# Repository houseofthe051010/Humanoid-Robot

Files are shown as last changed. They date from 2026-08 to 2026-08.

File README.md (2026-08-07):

# Humanoid Robot

This is my project to build a human-sized bipedal robot. In this repo I have all my current designs for my robot's shin and lower leg, and the iterations of gearboxes I have made for my actuators.

Right now, I am using pre-made actuators and am waiting on a grant to further complete my robot.

This grant is for building and testing the robot's two lower-leg and ankle assemblies. It is the first stage of the humanoid and is not funding the complete robot.

This is the current prototype, showing both lower-leg assemblies side by side.

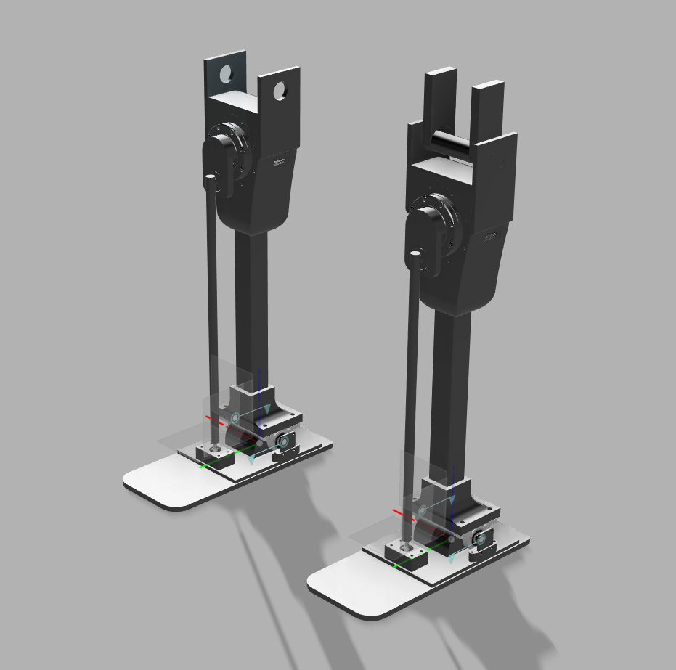
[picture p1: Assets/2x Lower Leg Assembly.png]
Two lower-leg prototype assemblies


## Electronics

Each ankle motor is controlled by a single-axis ODrive 3.6 clone. Both ODrives share one CAN bus with an STM32F103. The ODrives run the motor-control loops; the STM32 relays position commands from a Raspberry Pi 5 over SPI. UART is available for setup and debugging.

This is a wiring diagram of how i'll utilize CAN buses for each motor [`Schematics/`](Schematics/).

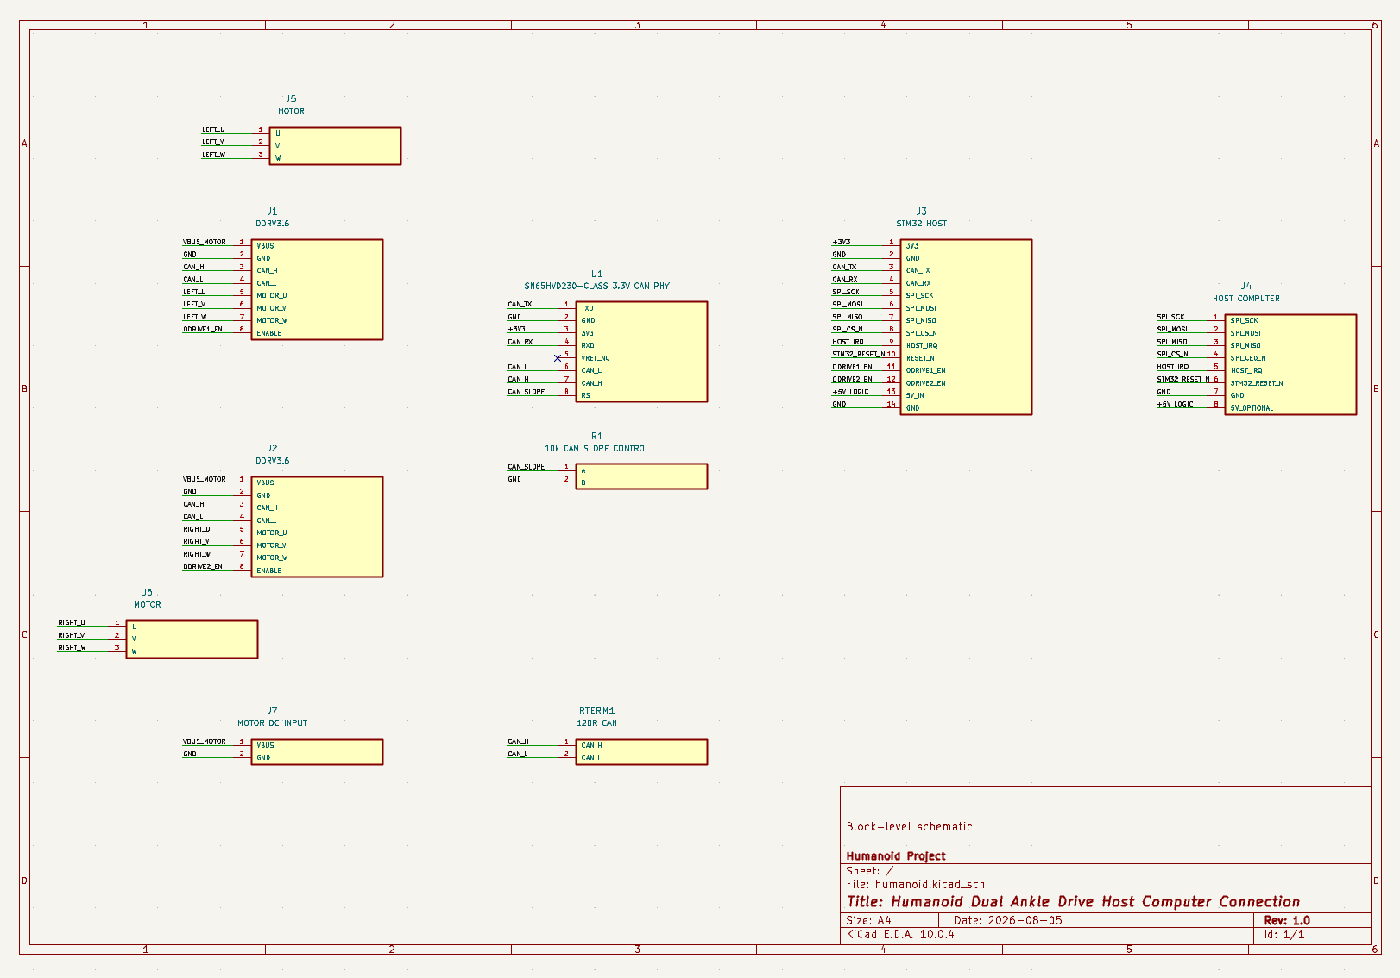
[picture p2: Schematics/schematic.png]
Electronics architecture


## Design

At first, I was thinking of a 2-DOF ankle design but now I am thinking of 1-DOF as its much cheaper and is really what I need. This came from a lot of thinking, as I am utilizing a lot of plastic for this build (though I will utilize aluminum in places where necessary). A lot of my body will be plastic and needs to be designed appropriately to support a bipedal's weight that is 5 foot tall. Currently I have a 1-dof ankle structure with a linkage system for only ankle pitch motion.

A bipedal can easily walk on level ground with ankle pitch. I have also attached a 50mm bearing hole for attaching the knee.

I also kept my earlier 2-DOF single-leg assembly as a backup in case I return to a 2-DOF ankle in the future.

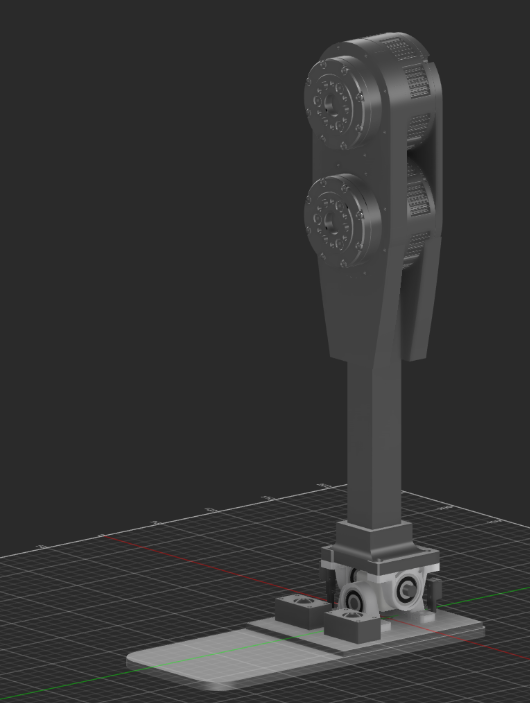
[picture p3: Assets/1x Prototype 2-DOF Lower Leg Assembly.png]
Backup 2-DOF lower-leg assembly


## Gearbox designs

The [`CAD/Actuators/`](CAD/Actuators/) folder has my custom planetary and cycloidal C6374 designs.

These gearboxes were built by me as a part of prototyping and learning on how to make my robot. They are there as they helped me decide how to make my robot and what actuators to use. I chose the cyclodial gearbox over the plantery in my design as it was easier to print with lower backlash, had high reductions, and was stronger, giving me 50+nm torque around 100mm size. Though, I chose to use a pre-built one as it was much less complex. 

## Bill of materials

This table shows the full replication cost. My current Macondo grant request is only $360 for the parts I still need; the rest are already owned or outside this grant request.

| Category | Item | Quantity | Unit price (USD) | Line total (USD) | Product link |
| --- | --- | ---: | ---: | ---: | --- |
| Actuation | SteadyWin GIM6010-48 48:1 planetary geared ankle motor, without driver | 2 | $156.00 | $312.00 | [Buy](https://rcdrone.top/products/steadywin-gim6010-48-planetary-reducer-servo-motor) |
| Structure | 6061-T6 aluminum square tubing, 1 in x 1 in x 0.125 in wall x 24 in | 2 | $14.89 | $29.78 | [Buy](https://www.onlinemetals.com/en/buy/aluminum/1-x-0-125-aluminum-square-tube-6061-t6-extruded/pid/18014) |
| Fabrication | SUNLU PA6-CF black filament, 1.75 mm, 1 kg, 80% PA / 20% carbon fiber | 1 | $44.99 | $44.99 | [Buy](https://store.sunlu.com/products/nylon6-carbon-fiber-pa6-cf-3d-printer-filament-1kg) |
| Mechanical | KP08 pillow block bearing, 8 mm bore | 10 | $2.95 | $29.50 | [Buy](https://www.crcibernetica.com/8-mm-pillow-block-mounted-ball-bearing-kp08/) |
| Mechanical | M3 stainless-steel bolt, nut, flat-washer and spring-washer assortment, 720 pieces | 1 | $9.99 | $9.99 | [Buy](https://www.amazon.com/dp/B0FG2BRXL3) |
| Motor control | ODrive S V3.6 FOC single-axis BLDC motor controller, 60 A, CAN/PWM | 2 | $31.61 | $63.22 | [Buy](https://www.banggood.com/ODrive-S-V3_6-FOC-BLDC-Motor-Controller-60A-Support-CAN-PWM-Pulse-Encoder-TLE5012B-AS5047-AMT10X-MT6816-ARM-Cortex-M4-p-2043307.html) |
| CAN bus | SN65HVD230 3.3 V CAN bus transceiver module | 1 | $0.94 | $0.94 | [Buy](https://www.aliexpress.com/item/1005008512626947.html) |
| CAN bus | 120 ohm 1/4 W 1% metal-film termination resistors, 100-pack | 1 | $0.94 | $0.94 | [Buy](https://www.aliexpress.com/item/32526023399.html) |
| Electronics | 10 kOhm 1/4 W metal-film resistors, 100-pack | 1 | $0.50 | $0.50 | [Buy](https://www.aliexpress.com/item/1005006006915852.html) |
| Power | XT60 male and female connector set, 5 pairs | 1 | $5.60 | $5.60 | [Buy](https://www.aliexpress.com/item/1005009991978695.html) |
| Wiring | Variable-AWG wire allowance | 1 | $20.00 | $20.00 | [Reference](https://www.aliexpress.com/item/4001131337448.html) |
| Embedded control | STM32F103C8T6 Blue Pill development board, pre-soldered | 1 | $8.99 | $8.99 | [Buy](https://shillehtek.com/products/shillehtek-pre-soldered-authentic-stm32f103c8t6-arm-stm32) |
| Host computing | Raspberry Pi 5 Desktop Kit, 8 GB (host computer, storage, power, cooling, and accessories) | 1 | $235.00 | $235.00 | [Buy](https://www.canakit.com/official-raspberry-pi-5-desktop-kit.html) |
| **Total** |  |  |  | **$761.45** |  |

## Assembly instructions

1. Print the parts in [`CAD/Assembly/Individual STLs/`](CAD/Assembly/Individual%20STLs/) using PA6-CF. The STL names match their source STEP names.
2. Fit the two `Foot Mounting Plate` parts and `Rounded Bearing Support` to the `Foot Base`, then install the purchased pillow-block bearings on the pitch axis.
3. Attach the `Shin Support Attachment` and cut the aluminum shin tube to 200 mm. Drill the tube from the CAD hole locations, then fasten it with M3 hardware.
4. Use the `Electronics Mounting Tray` and `Encoder Holder` parts for the controller and encoder mounting points. The `Lower Leg Support Assembly` STEP files can be used as reference assemblies.
5. Mount one motor and one ODrive to each lower leg. Confirm that both ankles move freely by hand before applying power.
6. Wire and test one motor at a time with the ankle unloaded. 

### Power and signal wiring

- Use a current-limited 50 V bench supply rated for at least 10 A per motor, or 20 A when both motors  run together.
- The 50 V rail connects only to the ODrive power inputs. Power the STM32, CAN transceiver, and Raspberry Pi from their voltage regulations with GND connections.
- Connect STM32 CAN to Odrive CAN, merging them as you connect them, and UART to host computer.

## STM32 controller firmware

This protocol is used for Odrive comms: [ODrive v3.x CANSimple protocol](https://github.com/odriverobotics/ODrive/tree/master/Firmware/communication/can). UART can also be used for testing.

The first ODrive uses CAN ID `0` and the second ID `1` at 500 kbit/s. The Raspberry Pi helper in controls them as the host [`Code/rpi_host/ankle_controller.py`](Code/rpi_host/ankle_controller.py) has position, enable, idle, and stop commands. This was used to test my custom gearboxes.

### Build and flash with ST-Link

Connect the ST-LINK to the STM32. 

```text
cd Code/stm32_controller
pio run
pio run -t upload
pio device monitor -b 115200
```

## Notes

This is a long project, and I don't think macondo runs long enough for me to complete it, which is why i'm completing the lower leg first, and then will add on in different hack club events.

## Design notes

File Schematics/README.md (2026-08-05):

# Electronics Schematic

This is a schematic of my electronics architecture and the wiring and connections between each component. It is not a PCB design because the PCBs are prebuilt and bought separately.

Electronics architecture

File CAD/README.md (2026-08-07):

# CAD

Source CAD and STEP files for the robot are here. The actuator gearbox designs are in [`Actuators/`](Actuators/), and the shin, ankle, and feet assembly is in [`Assembly/`](Assembly/).

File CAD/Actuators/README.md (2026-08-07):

# Actuators

This folder contains the source CAD and STEP files for the gearbox designs I'm developing for my C6374 motors.

## Print settings

- Material: PA6-CF
- Infill: 100%
- Walls: maximum
- Printer: Anycubic Kobra S1

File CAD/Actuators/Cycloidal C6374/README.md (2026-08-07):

# Cycloidal C6374 Gearbox

This is where you'll find the source CAD, STEP, and printable STL files for the cycloidal gearbox I designed for my C6374 motor.

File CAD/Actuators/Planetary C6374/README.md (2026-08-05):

# Planetary C6374 Gearbox

This is where you'll find the source CAD and STEP files for the planetary gearbox I designed for my C6374 motor.

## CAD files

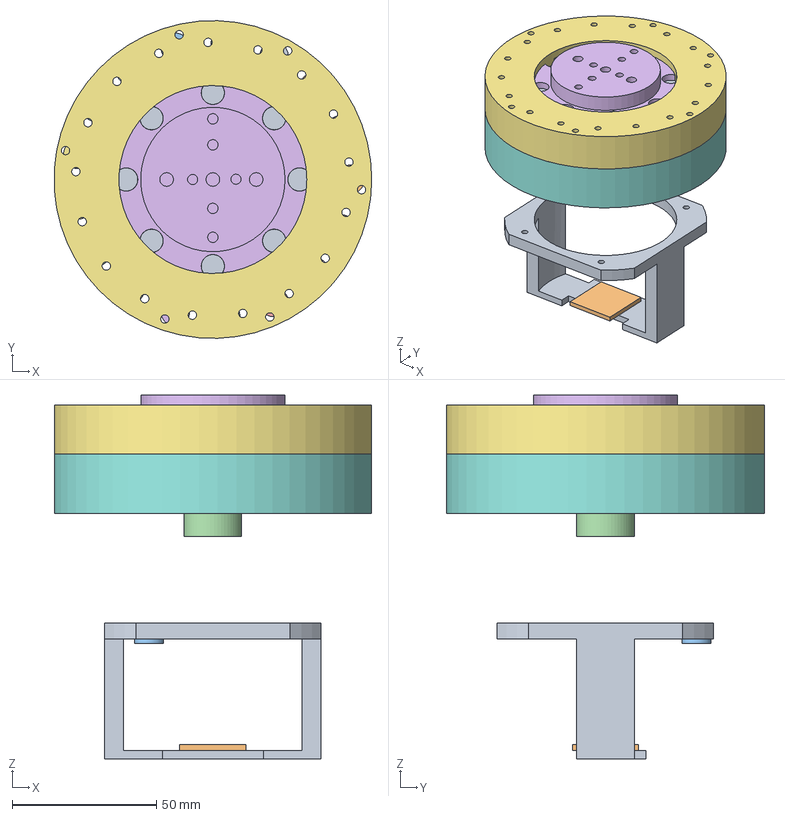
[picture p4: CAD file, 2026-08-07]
CAD/Actuators/Cycloidal C6374/Individual STEPs/10 - Cycloidal Output and Encoder Assembly.step
109.9 x 110.0 x 126.0 mm

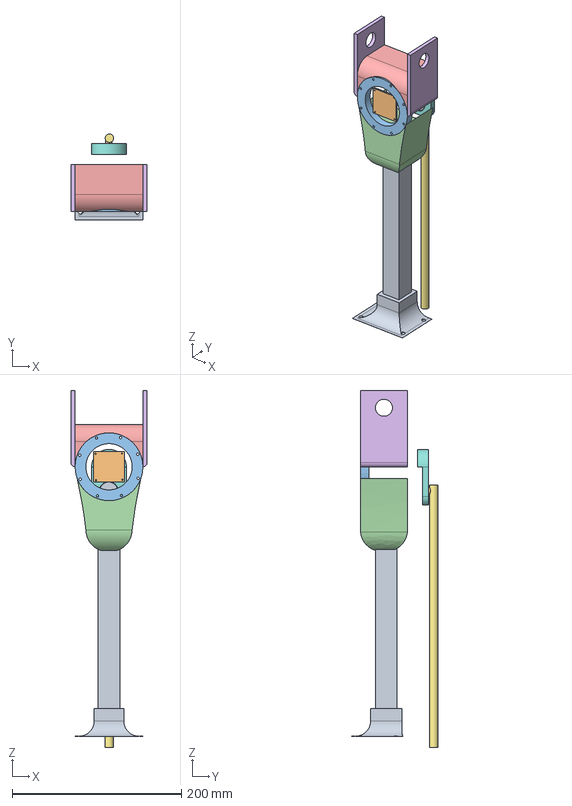
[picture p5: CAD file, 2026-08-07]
CAD/Assembly/Individual STEPs/16 - Lower Leg Support Assembly 1.step
90.0 x 101.6 x 421.3 mm

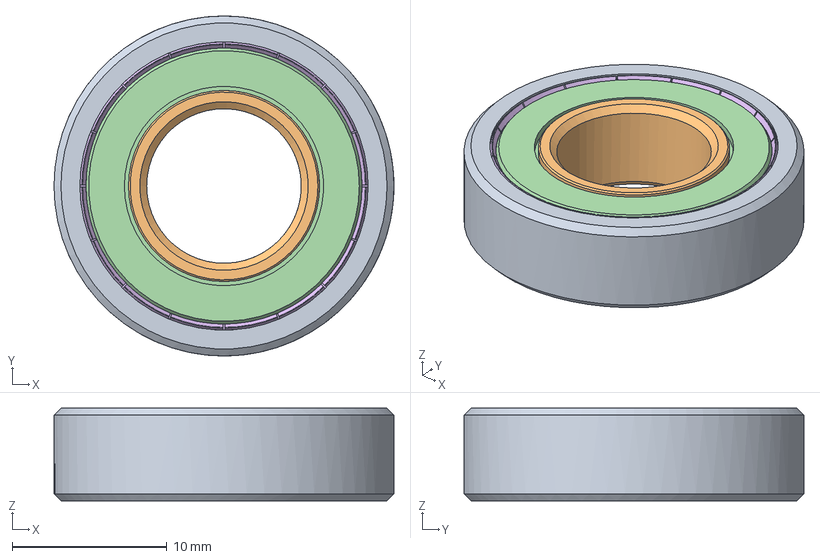
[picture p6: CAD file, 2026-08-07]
CAD/Actuators/Cycloidal C6374/Individual STEPs/07 - 6900Z Ball Bearing.step
22.0 x 22.0 x 6.00 mm

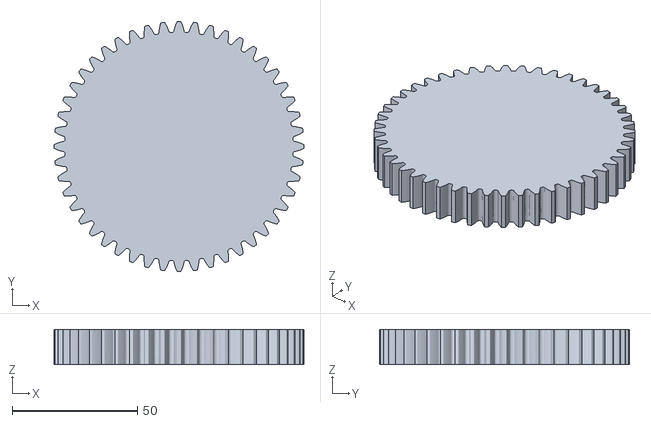
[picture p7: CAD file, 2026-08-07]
CAD/Actuators/Planetary C6374/Individual STLs/04 - Spur Gear - 48 Teeth.stl
100.0 x 100.0 x 14.0

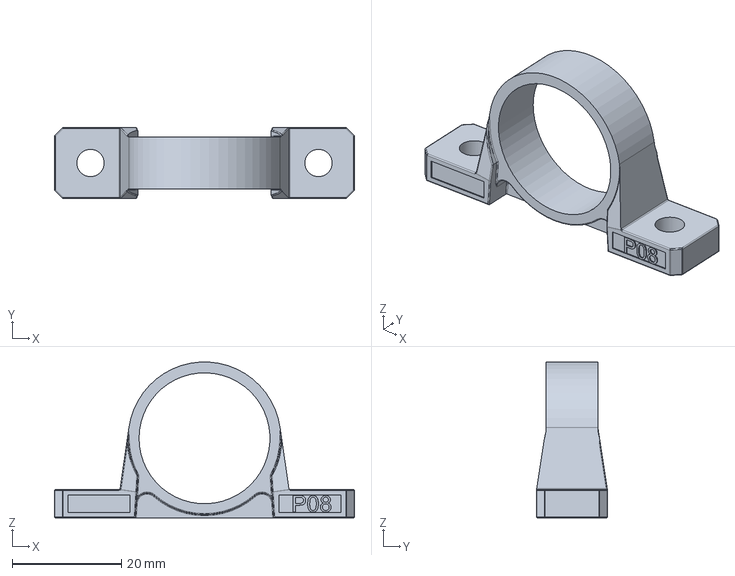
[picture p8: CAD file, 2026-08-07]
CAD/Assembly/Individual STEPs/10 - Pillow Block Bearing 1.step
55.0 x 13.0 x 28.6 mm

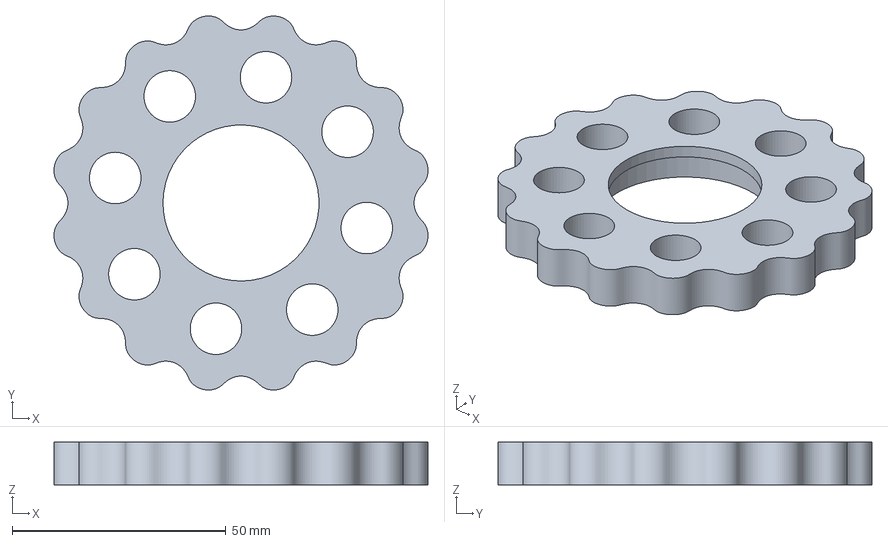
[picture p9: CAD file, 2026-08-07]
CAD/Actuators/Cycloidal C6374/Individual STEPs/05 - Cycloidal Disk 1.step
87.5 x 87.5 x 10.0 mm

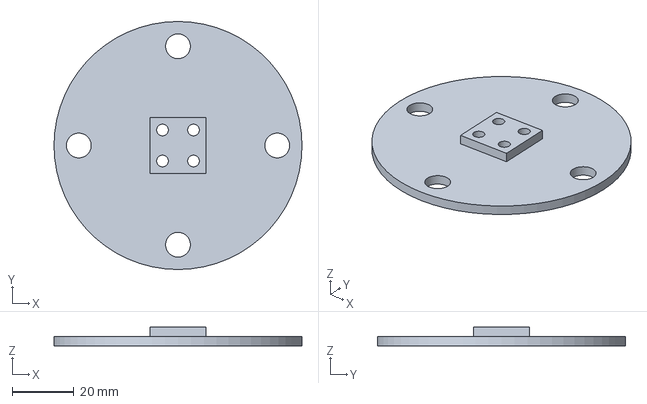
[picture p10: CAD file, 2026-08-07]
CAD/Actuators/Planetary C6374/Individual STEPs/09 - Motor Case Attachment.step
80.0 x 80.0 x 6.00 mm

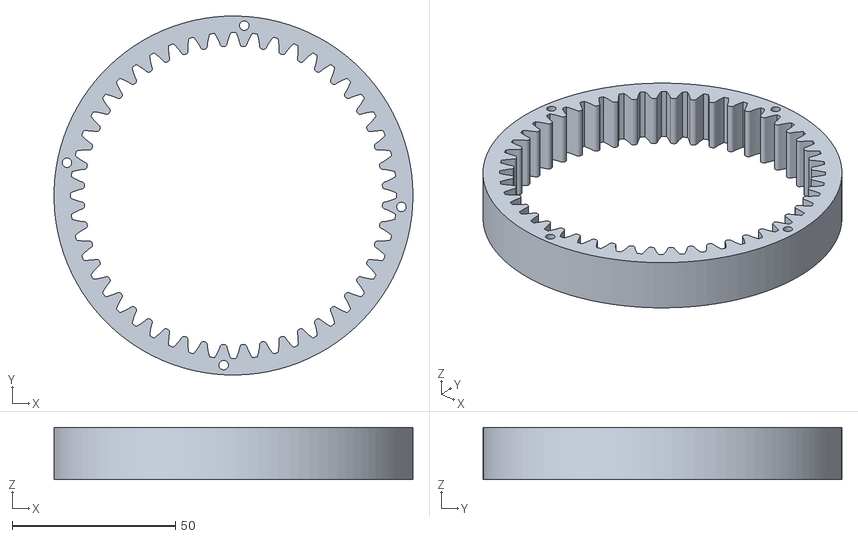
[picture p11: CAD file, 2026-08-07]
CAD/Actuators/Planetary C6374/Individual STLs/13 - Ring Shell.stl
110.0 x 110.0 x 16.0

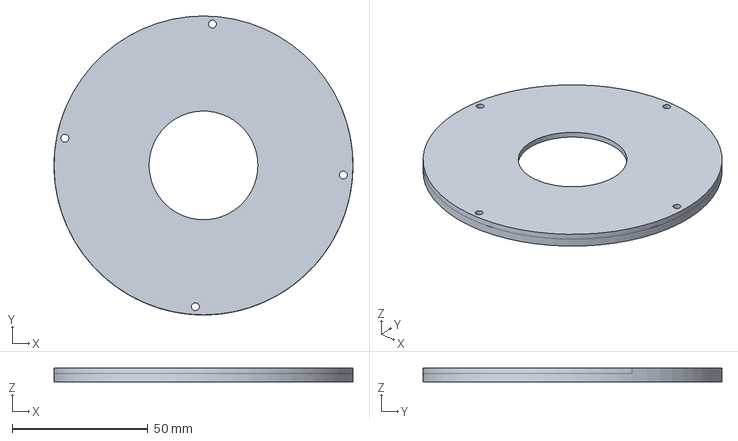
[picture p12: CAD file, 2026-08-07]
CAD/Actuators/Planetary C6374/Individual STEPs/11 - Middle Cover.step
110.0 x 110.0 x 5.00 mm

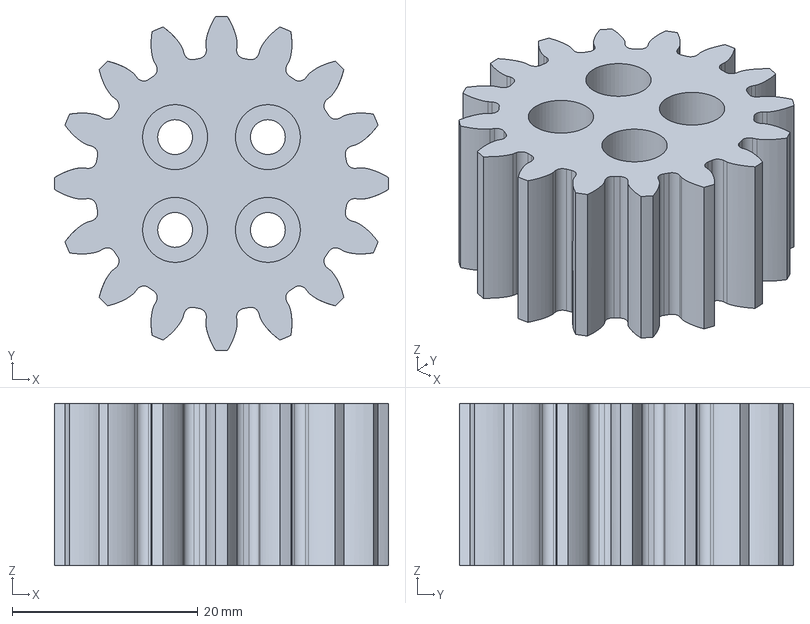
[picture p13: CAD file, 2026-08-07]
CAD/Actuators/Planetary C6374/Individual STEPs/07 - Second-Stage Sun Gear.step
36.0 x 36.0 x 17.5 mm

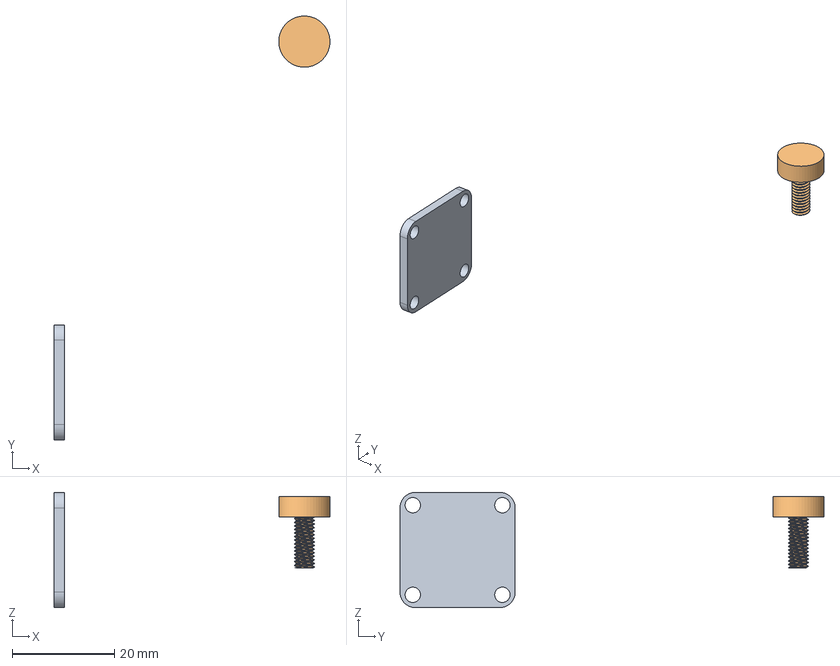
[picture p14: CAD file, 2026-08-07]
CAD/Assembly/Individual STEPs/20 - Encoder Holder 2.step
53.9 x 82.8 x 22.5 mm

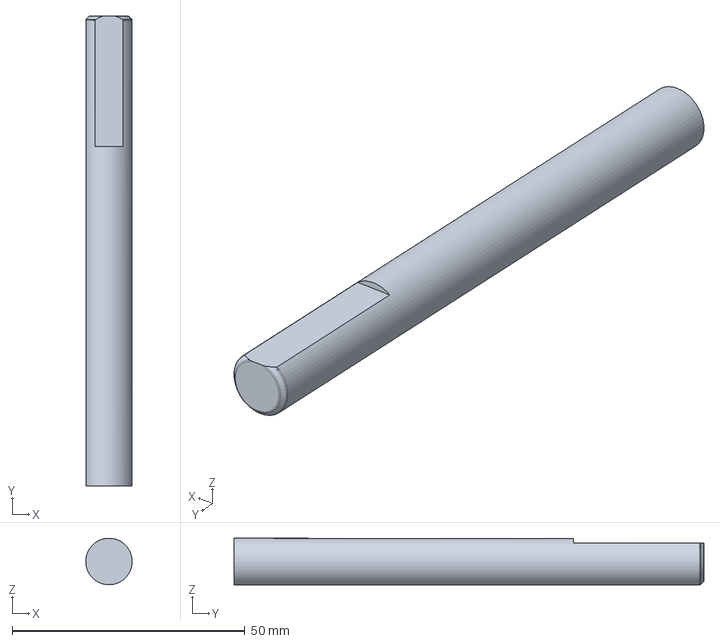
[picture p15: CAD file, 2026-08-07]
CAD/Actuators/Cycloidal C6374/Individual STEPs/08 - Eccentric Shaft.step
9.99 x 101.0 x 10.00 mm

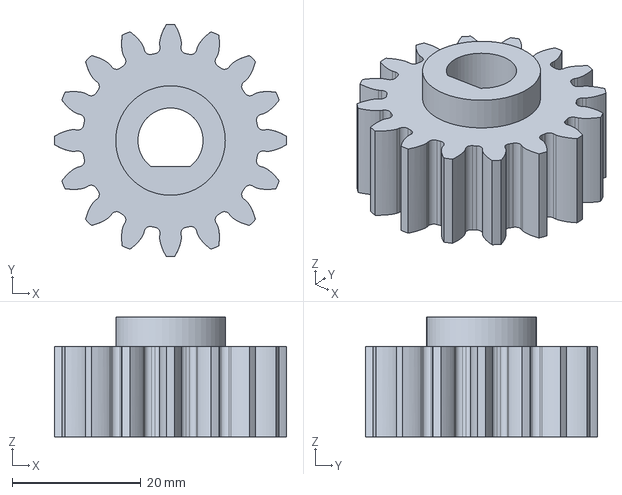
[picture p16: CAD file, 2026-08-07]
CAD/Actuators/Planetary C6374/Individual STEPs/06 - Sun Gear.step
36.0 x 36.0 x 18.6 mm

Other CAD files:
CAD/Assembly/Individual STEPs/21 - Lower Leg Support Assembly 2.step
CAD/Actuators/Planetary C6374/Individual STEPs/01 - 6900Z Ball Bearing.step
CAD/Assembly/Individual STEPs/17 - Pillow Block Bearing 3.step
CAD/Actuators/Cycloidal C6374/Individual STEPs/06 - Cycloidal Disk 2.step
CAD/Assembly/Individual STEPs/11 - Pillow Block Bearing 2.step
CAD/Actuators/Cycloidal C6374/Individual STEPs/01 - 6806RS Bearing.step
CAD/Actuators/Cycloidal C6374/Individual STEPs/03 - Cycloidal Gearbox Housing.step
CAD/Actuators/Cycloidal C6374/Individual STLs/03 - Cycloidal Gearbox Housing.stl
CAD/Actuators/Cycloidal C6374/Individual STLs/05 - Cycloidal Disk 1.stl
CAD/Actuators/Cycloidal C6374/Individual STLs/06 - Cycloidal Disk 2.stl
CAD/Actuators/Planetary C6374/Individual STEPs/02 - Gear Output Stabilizer Output Shaft.step
CAD/Actuators/Planetary C6374/Individual STEPs/05 - Planet Gear.step
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

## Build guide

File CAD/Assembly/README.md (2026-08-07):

# Shin, Ankle, and Feet Assembly

## Print settings

- Material: PA6-CF
- Infill: 100%
- Walls: maximum
- Printer: Anycubic Kobra S1

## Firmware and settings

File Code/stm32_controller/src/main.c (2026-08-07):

#include "stm32f1xx_hal.h"

#include <stdio.h>
#include <stdlib.h>
#include <string.h>

#include "odrive_can.h"

CAN_HandleTypeDef hcan;
SPI_HandleTypeDef hspi1;
UART_HandleTypeDef huart1;

enum {
    HOST_NOP = 0,
    HOST_MOVE_POSITION = 1,
    HOST_ENABLE = 2,
    HOST_IDLE = 3,
    HOST_ESTOP = 4,
    HOST_CLEAR_ERRORS = 5,
};

typedef struct __attribute__((packed)) {
    uint8_t magic;
    uint8_t command;
    uint8_t motor;
    uint8_t sequence;
    float position_turns;
    float velocity_ff_turns_s;
    float torque_ff_nm;
    uint8_t reserved[8];
} HostRequest;

typedef struct __attribute__((packed)) {
    uint8_t magic;
    uint8_t status;
    uint8_t last_command;
    uint8_t sequence;
    float position_turns[2];
    float velocity_turns_s[2];
    uint32_t combined_axis_error;
} HostResponse;

_Static_assert(sizeof(HostRequest) == 24, "HostRequest must be 24 bytes");
_Static_assert(sizeof(HostResponse) == 24, "HostResponse must be 24 bytes");

static uint8_t spi_rx[sizeof(HostRequest)];
static uint8_t spi_tx[sizeof(HostResponse)];
static volatile uint8_t command_ready;
static HostRequest pending_command;
static uint8_t last_status;

static void SystemClock_Config(void);
static void GPIO_Init(void);
static void CAN_Init(void);
static void SPI1_Init(void);
static void UART1_Init(void);
static void Error_Handler(void);

static void uart_write(const char *text) {
    HAL_UART_Transmit(&huart1, (uint8_t *)text, (uint16_t)strlen(text), 100);
}

static bool valid_motor(uint8_t motor) {
    return motor < ODRIVE_COUNT;
}

static uint8_t execute_command(const HostRequest *request) {
    bool ok = false;
    if (request == NULL || request->magic != 0xA5U) return 1;

    switch (request->command) {
        case HOST_NOP: return 0;
        case HOST_MOVE_POSITION:
            if (!valid_motor(request->motor)) return 2;
            ok = odrive_set_position(request->motor, request->position_turns,
                                     request->velocity_ff_turns_s,
                                     request->torque_ff_nm);
            break;
        case HOST_ENABLE:
            if (!valid_motor(request->motor)) return 2;
            ok = odrive_enable_position_control(request->motor);
            break;
        case HOST_IDLE:
            if (!valid_motor(request->motor)) return 2;
            ok = odrive_set_idle(request->motor);
            break;
        case HOST_ESTOP:
            ok = odrive_estop_all();
            break;
        case HOST_CLEAR_ERRORS:
            if (!valid_motor(request->motor)) return 2;
            ok = odrive_clear_errors(request->motor);
            break;
        default: return 3;
    }
    return ok ? 0 : 4;
}

static void prepare_response(uint8_t command, uint8_t sequence) {
    HostResponse response = {0};
    response.magic = 0x5AU;
    response.status = last_status;
    response.last_command = command;
    response.sequence = sequence;
    for (uint8_t node = 0; node < ODRIVE_COUNT; ++node) {
        const ODriveFeedback *value = odrive_feedback(node);
        response.position_turns[node] = value->position_turns;
        response.velocity_turns_s[node] = value->velocity_turns_s;
        response.combined_axis_error |= value->axis_error;
    }
    memcpy(spi_tx, &response, sizeof(response));
}

static void poll_uart(void) {
    static char line[64];
    static size_t length;
    uint8_t byte;
    if (HAL_UART_Receive(&huart1, &byte, 1, 0) != HAL_OK) return;

    if (byte == '\r' || byte == '\n') {
        line[length] = '\0';
        unsigned motor;
        float position;
        if (sscanf(line, "p %u %f", &motor, &position) == 2 && motor < ODRIVE_COUNT) {
            odrive_set_position((uint8_t)motor, position, 0.0f, 0.0f);
        } else if (sscanf(line, "enable %u", &motor) == 1 && motor < ODRIVE_COUNT) {
            odrive_enable_position_control((uint8_t)motor);
        } else if (sscanf(line, "idle %u", &motor) == 1 && motor < ODRIVE_COUNT) {
            odrive_set_idle((uint8_t)motor);
        } else if (sscanf(line, "clear %u", &motor) == 1 && motor < ODRIVE_COUNT) {
            odrive_clear_errors((uint8_t)motor);
        } else if (strcmp(line, "estop") == 0) {
            odrive_estop_all();
        } else if (length != 0U) {
            uart_write("Commands: p <0|1> <turns>, enable <0|1>, idle <0|1>, clear <0|1>, estop\r\n");
        }
        length = 0;
    } else if (length < sizeof(line) - 1U) {
        line[length++] = (char)byte;
    }
}

int main(void) {
    HAL_Init();
    SystemClock_Config();
    GPIO_Init();
    CAN_Init();
    SPI1_Init();
    UART1_Init();

    CAN_FilterTypeDef filter = {0};
    filter.FilterBank = 0;
    filter.FilterMode = CAN_FILTERMODE_IDMASK;
    filter.FilterScale = CAN_FILTERSCALE_32BIT;
    filter.FilterIdHigh = 0;
    filter.FilterIdLow = 0;
    filter.FilterMaskIdHigh = 0;
    filter.FilterMaskIdLow = 0;
    filter.FilterFIFOAssignment = CAN_RX_FIFO0;
    filter.FilterActivation = ENABLE;
    if (HAL_CAN_ConfigFilter(&hcan, &filter) != HAL_OK ||
        HAL_CAN_Start(&hcan) != HAL_OK ||
        HAL_CAN_ActivateNotification(&hcan, CAN_IT_RX_FIFO0_MSG_PENDING) != HAL_OK) {
        Error_Handler();
    }

    odrive_can_init(&hcan);
    prepare_response(HOST_NOP, 0);
    if (HAL_SPI_TransmitReceive_IT(&hspi1, spi_tx, spi_rx, sizeof(spi_rx)) != HAL_OK) {
        Error_Handler();
    }
    uart_write("Humanoid ankle controller ready; motors remain idle until enabled.\r\n");

    while (1) {
        if (command_ready != 0U) {
            HostRequest command;
            __disable_irq();
            memcpy(&command, &pending_command, sizeof(command));
            command_ready = 0;
            __enable_irq();
            if (command.command != HOST_NOP) {
                last_status = execute_command(&command);
                prepare_response(command.command, command.sequence);
            }
        }
        poll_uart();
    }
}

void HAL_CAN_RxFifo0MsgPendingCallback(CAN_HandleTypeDef *handle) {
    CAN_RxHeaderTypeDef header;
    uint8_t data[8];
    if (handle->Instance == CAN1 &&
        HAL_CAN_GetRxMessage(handle, CAN_RX_FIFO0, &header, data) == HAL_OK) {
        odrive_process_rx(&header, data);
    }
}

void HAL_SPI_TxRxCpltCallback(SPI_HandleTypeDef *handle) {
    if (handle->Instance != SPI1) return;
    if (command_ready == 0U) {
        memcpy(&pending_command, spi_rx, sizeof(pending_command));
        command_ready = 1U;
    }
    HAL_SPI_TransmitReceive_IT(&hspi1, spi_tx, spi_rx, sizeof(spi_rx));
}

void USB_LP_CAN1_RX0_IRQHandler(void) { HAL_CAN_IRQHandler(&hcan); }
void SPI1_IRQHandler(void) { HAL_SPI_IRQHandler(&hspi1); }

static void SystemClock_Config(void) {
    RCC_OscInitTypeDef oscillator = {0};
    RCC_ClkInitTypeDef clock = {0};
    oscillator.OscillatorType = RCC_OSCILLATORTYPE_HSE;
    oscillator.HSEState = RCC_HSE_ON;
    oscillator.HSEPredivValue = RCC_HSE_PREDIV_DIV1;
    oscillator.PLL.PLLState = RCC_PLL_ON;
    oscillator.PLL.PLLSource = RCC_PLLSOURCE_HSE;
    oscillator.PLL.PLLMUL = RCC_PLL_MUL9;
    if (HAL_RCC_OscConfig(&oscillator) != HAL_OK) Error_Handler();

    clock.ClockType = RCC_CLOCKTYPE_HCLK | RCC_CLOCKTYPE_SYSCLK |
                      RCC_CLOCKTYPE_PCLK1 | RCC_CLOCKTYPE_PCLK2;
    clock.SYSCLKSource = RCC_SYSCLKSOURCE_PLLCLK;
    clock.AHBCLKDivider = RCC_SYSCLK_DIV1;
    clock.APB1CLKDivider = RCC_HCLK_DIV2;
    clock.APB2CLKDivider = RCC_HCLK_DIV1;
    if (HAL_RCC_ClockConfig(&clock, FLASH_LATENCY_2) != HAL_OK) Error_Handler();
}

static void GPIO_Init(void) {
    __HAL_RCC_AFIO_CLK_ENABLE();
    __HAL_RCC_GPIOA_CLK_ENABLE();
    __HAL_AFIO_REMAP_SWJ_NOJTAG();
}

static void CAN_Init(void) {
    __HAL_RCC_CAN1_CLK_ENABLE();
    GPIO_InitTypeDef gpio = {0};
    gpio.Pin = GPIO_PIN_11;
    gpio.Mode = GPIO_MODE_INPUT;
    gpio.Pull = GPIO_NOPULL;
    HAL_GPIO_Init(GPIOA, &gpio);
    gpio.Pin = GPIO_PIN_12;
    gpio.Mode = GPIO_MODE_AF_PP;
    gpio.Speed = GPIO_SPEED_FREQ_HIGH;
    HAL_GPIO_Init(GPIOA, &gpio);

    hcan.Instance = CAN1;
    hcan.Init.Prescaler = 9;
    hcan.Init.Mode = CAN_MODE_NORMAL;
    hcan.Init.SyncJumpWidth = CAN_SJW_1TQ;
    hcan.Init.TimeSeg1 = CAN_BS1_6TQ;
    hcan.Init.TimeSeg2 = CAN_BS2_1TQ;
    hcan.Init.TimeTriggeredMode = DISABLE;
    hcan.Init.AutoBusOff = ENABLE;
    hcan.Init.AutoWakeUp = DISABLE;
    hcan.Init.AutoRetransmission = ENABLE;
    hcan.Init.ReceiveFifoLocked = DISABLE;
    hcan.Init.TransmitFifoPriority = DISABLE;
    if (HAL_CAN_Init(&hcan) != HAL_OK) Error_Handler();
    HAL_NVIC_SetPriority(USB_LP_CAN1_RX0_IRQn, 1, 0);
    HAL_NVIC_EnableIRQ(USB_LP_CAN1_RX0_IRQn);
}

static void SPI1_Init(void) {
    __HAL_RCC_SPI1_CLK_ENABLE();
    GPIO_InitTypeDef gpio = {0};
    gpio.Pin = GPIO_PIN_4 | GPIO_PIN_5 | GPIO_PIN_7;
    gpio.Mode = GPIO_MODE_INPUT;
    gpio.Pull = GPIO_NOPULL;
    HAL_GPIO_Init(GPIOA, &gpio);
    gpio.Pin = GPIO_PIN_6;
    gpio.Mode = GPIO_MODE_AF_PP;
    gpio.Speed = GPIO_SPEED_FREQ_HIGH;
    HAL_GPIO_Init(GPIOA, &gpio);

    hspi1.Instance = SPI1;
    hspi1.Init.Mode = SPI_MODE_SLAVE;
    hspi1.Init.Direction = SPI_DIRECTION_2LINES;
    hspi1.Init.DataSize = SPI_DATASIZE_8BIT;
    hspi1.Init.CLKPolarity = SPI_POLARITY_LOW;
    hspi1.Init.CLKPhase = SPI_PHASE_1EDGE;
    hspi1.Init.NSS = SPI_NSS_HARD_INPUT;
    hspi1.Init.FirstBit = SPI_FIRSTBIT_MSB;
    hspi1.Init.TIMode = SPI_TIMODE_DISABLE;
    hspi1.Init.CRCCalculation = SPI_CRCCALCULATION_DISABLE;
    hspi1.Init.CRCPolynomial = 7;
    if (HAL_SPI_Init(&hspi1) != HAL_OK) Error_Handler();
    HAL_NVIC_SetPriority(SPI1_IRQn, 2, 0);
    HAL_NVIC_EnableIRQ(SPI1_IRQn);
}

static void UART1_Init(void) {
    __HAL_RCC_USART1_CLK_ENABLE();
    GPIO_InitTypeDef gpio = {0};
    gpio.Pin = GPIO_PIN_9;
    gpio.Mode = GPIO_MODE_AF_PP;
    gpio.Speed = GPIO_SPEED_FREQ_HIGH;
    HAL_GPIO_Init(GPIOA, &gpio);
    gpio.Pin = GPIO_PIN_10;
    gpio.Mode = GPIO_MODE_INPUT;
    gpio.Pull = GPIO_NOPULL;
    HAL_GPIO_Init(GPIOA, &gpio);

    huart1.Instance = USART1;
    huart1.Init.BaudRate = 115200;
    huart1.Init.WordLength = UART_WORDLENGTH_8B;
    huart1.Init.StopBits = UART_STOPBITS_1;
    huart1.Init.Parity = UART_PARITY_NONE;
    huart1.Init.Mode = UART_MODE_TX_RX;
    huart1.Init.HwFlowCtl = UART_HWCONTROL_NONE;
    huart1.Init.OverSampling = UART_OVERSAMPLING_16;
    if (HAL_UART_Init(&huart1) != HAL_OK) Error_Handler();
}

static void Error_Handler(void) {
    __disable_irq();
    while (1) { }
}

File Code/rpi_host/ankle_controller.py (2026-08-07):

"""Minimal Raspberry Pi SPI interface for the STM32 ankle controller."""

from dataclasses import dataclass
import struct
import time

import spidev


REQUEST = struct.Struct("<BBBBfff8x")
RESPONSE = struct.Struct("<BBBBffffI")


@dataclass
class Feedback:
    status: int
    last_command: int
    sequence: int
    position_turns: tuple[float, float]
    velocity_turns_s: tuple[float, float]
    combined_axis_error: int


class AnkleController:
    MOVE_POSITION = 1
    ENABLE = 2
    IDLE = 3
    ESTOP = 4
    CLEAR_ERRORS = 5

    def __init__(self, bus: int = 0, chip_select: int = 0, speed_hz: int = 500_000):
        self.spi = spidev.SpiDev()
        self.spi.open(bus, chip_select)
        self.spi.max_speed_hz = speed_hz
        self.spi.mode = 0
        self.sequence = 0

    def close(self) -> None:
        self.spi.close()

    def _command(
        self,
        command: int,
        motor: int = 0,
        position_turns: float = 0.0,
        velocity_ff_turns_s: float = 0.0,
        torque_ff_nm: float = 0.0,
    ) -> Feedback:
        if motor not in (0, 1):
            raise ValueError("motor must be 0 or 1")
        self.sequence = (self.sequence + 1) & 0xFF
        request = REQUEST.pack(
            0xA5,
            command,
            motor,
            self.sequence,
            position_turns,
            velocity_ff_turns_s,
            torque_ff_nm,
        )
        self.spi.xfer2(list(request))

        # SPI is full-duplex, so the command result is returned by the next
        # transfer. Poll with NOP packets until the STM32 reports this sequence.
        nop = REQUEST.pack(0xA5, 0, motor, self.sequence, 0.0, 0.0, 0.0)
        values = None
        for _ in range(10):
            time.sleep(0.002)
            candidate = RESPONSE.unpack(bytes(self.spi.xfer2(list(nop))))
            if candidate[0] == 0x5A and candidate[2] == command and candidate[3] == self.sequence:
                values = candidate
                break
        if values is None:
            raise TimeoutError("STM32 did not acknowledge the SPI command")
        if values[0] != 0x5A:
            raise RuntimeError("invalid response from STM32")
        return Feedback(
            status=values[1],
            last_command=values[2],
            sequence=values[3],
            position_turns=(values[4], values[5]),
            velocity_turns_s=(values[6], values[7]),
            combined_axis_error=values[8],
        )

    def move_position(
        self,
        motor: int,
        position_turns: float,
        velocity_ff_turns_s: float = 0.0,
        torque_ff_nm: float = 0.0,
    ) -> Feedback:
        return self._command(
            self.MOVE_POSITION,
            motor,
            position_turns,
            velocity_ff_turns_s,
            torque_ff_nm,
        )

    def enable(self, motor: int) -> Feedback:
        return self._command(self.ENABLE, motor)

    def idle(self, motor: int) -> Feedback:
        return self._command(self.IDLE, motor)

    def clear_errors(self, motor: int) -> Feedback:
        return self._command(self.CLEAR_ERRORS, motor)

    def emergency_stop(self) -> Feedback:
        return self._command(self.ESTOP)

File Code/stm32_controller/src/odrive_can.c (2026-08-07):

#include "odrive_can.h"

#include <string.h>

enum {
    CAN_CMD_HEARTBEAT = 0x01,
    CAN_CMD_ESTOP = 0x02,
    CAN_CMD_SET_AXIS_STATE = 0x07,
    CAN_CMD_ENCODER_ESTIMATES = 0x09,
    CAN_CMD_SET_CONTROLLER_MODES = 0x0B,
    CAN_CMD_SET_INPUT_POSITION = 0x0C,
    CAN_CMD_CLEAR_ERRORS = 0x18,
};

enum {
    AXIS_STATE_IDLE = 1,
    AXIS_STATE_CLOSED_LOOP_CONTROL = 8,
    CONTROL_MODE_POSITION = 3,
    INPUT_MODE_PASSTHROUGH = 1,
};

static CAN_HandleTypeDef *odrive_can;
static ODriveFeedback feedback[ODRIVE_COUNT];

static uint32_t make_id(uint8_t node_id, uint8_t command_id) {
    return ((uint32_t)node_id << 5U) | command_id;
}

static bool send_frame(uint8_t node_id, uint8_t command_id,
                       const uint8_t *data, uint8_t length) {
    CAN_TxHeaderTypeDef header = {0};
    uint32_t mailbox;
    uint8_t payload[8] = {0};

    if (odrive_can == NULL || length > sizeof(payload)) {
        return false;
    }
    if (data != NULL && length != 0U) {
        memcpy(payload, data, length);
    }
    header.StdId = make_id(node_id, command_id);
    header.IDE = CAN_ID_STD;
    header.RTR = CAN_RTR_DATA;
    header.DLC = length;
    header.TransmitGlobalTime = DISABLE;
    return HAL_CAN_AddTxMessage(odrive_can, &header, payload, &mailbox) == HAL_OK;
}

static void put_u32_le(uint8_t *destination, uint32_t value) {
    destination[0] = (uint8_t)value;
    destination[1] = (uint8_t)(value >> 8U);
    destination[2] = (uint8_t)(value >> 16U);
    destination[3] = (uint8_t)(value >> 24U);
}

static uint32_t get_u32_le(const uint8_t *source) {
    return (uint32_t)source[0] | ((uint32_t)source[1] << 8U) |
           ((uint32_t)source[2] << 16U) | ((uint32_t)source[3] << 24U);
}

static void put_float_le(uint8_t *destination, float value) {
    uint32_t bits;
    memcpy(&bits, &value, sizeof(bits));
    put_u32_le(destination, bits);
}

static float get_float_le(const uint8_t *source) {
    uint32_t bits = get_u32_le(source);
    float value;
    memcpy(&value, &bits, sizeof(value));
    return value;
}

static int16_t scaled_i16(float value, float scale) {
    float scaled = value * scale;
    if (scaled > 32767.0f) scaled = 32767.0f;
    if (scaled < -32768.0f) scaled = -32768.0f;
    return (int16_t)scaled;
}

void odrive_can_init(CAN_HandleTypeDef *can_handle) {
    odrive_can = can_handle;
    memset(feedback, 0, sizeof(feedback));
}

bool odrive_set_position(uint8_t node_id, float position_turns,
                         float velocity_ff_turns_s, float torque_ff_nm) {
    uint8_t data[8];
    int16_t velocity = scaled_i16(velocity_ff_turns_s, 1000.0f);
    int16_t torque = scaled_i16(torque_ff_nm, 1000.0f);

    if (node_id >= ODRIVE_COUNT) return false;
    put_float_le(data, position_turns);
    data[4] = (uint8_t)velocity;
    data[5] = (uint8_t)((uint16_t)velocity >> 8U);
    data[6] = (uint8_t)torque;
    data[7] = (uint8_t)((uint16_t)torque >> 8U);
    return send_frame(node_id, CAN_CMD_SET_INPUT_POSITION, data, sizeof(data));
}

bool odrive_enable_position_control(uint8_t node_id) {
    uint8_t modes[8];
    uint8_t state[4];
    if (node_id >= ODRIVE_COUNT) return false;
    put_u32_le(modes, CONTROL_MODE_POSITION);
    put_u32_le(modes + 4, INPUT_MODE_PASSTHROUGH);
    put_u32_le(state, AXIS_STATE_CLOSED_LOOP_CONTROL);
    return send_frame(node_id, CAN_CMD_SET_CONTROLLER_MODES, modes, sizeof(modes)) &&
           send_frame(node_id, CAN_CMD_SET_AXIS_STATE, state, sizeof(state));
}

bool odrive_set_idle(uint8_t node_id) {
    uint8_t state[4];
    if (node_id >= ODRIVE_COUNT) return false;
    put_u32_le(state, AXIS_STATE_IDLE);
    return send_frame(node_id, CAN_CMD_SET_AXIS_STATE, state, sizeof(state));
}

bool odrive_clear_errors(uint8_t node_id) {
    return node_id < ODRIVE_COUNT && send_frame(node_id, CAN_CMD_CLEAR_ERRORS, NULL, 0);
}

bool odrive_estop_all(void) {
    bool success = true;
    for (uint8_t node = 0; node < ODRIVE_COUNT; ++node) {
        success = send_frame(node, CAN_CMD_ESTOP, NULL, 0) && success;
    }
    return success;
}

void odrive_process_rx(const CAN_RxHeaderTypeDef *header, const uint8_t data[8]) {
    if (header == NULL || header->IDE != CAN_ID_STD) return;
    uint8_t node = (uint8_t)(header->StdId >> 5U);
    uint8_t command = (uint8_t)(header->StdId & 0x1FU);
    if (node >= ODRIVE_COUNT) return;

    if (command == CAN_CMD_HEARTBEAT && header->DLC >= 5U) {
        feedback[node].axis_error = get_u32_le(data);
        feedback[node].axis_state = data[4];
        feedback[node].last_update_ms = HAL_GetTick();
    } else if (command == CAN_CMD_ENCODER_ESTIMATES && header->DLC == 8U) {
        feedback[node].position_turns = get_float_le(data);
        feedback[node].velocity_turns_s = get_float_le(data + 4);
        feedback[node].last_update_ms = HAL_GetTick();
    }
}

const ODriveFeedback *odrive_feedback(uint8_t node_id) {
    return node_id < ODRIVE_COUNT ? &feedback[node_id] : NULL;
}

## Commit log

2026-10-26 Restore current browser journals and pasted pictures
2026-10-28 Restore original illustrated lower-leg README
2026-10-29 Update humanoid BOM with GDZ468H drivers and JP40 cells
2026-10-29 Update humanoid BOM prices and remove TBD items
2026-10-29 Classify BOM procurement and consolidate screw hardware
2026-10-29 Simplify BOM and consolidate shared 5V supply
2026-10-31 Refresh submission README, schematic and BOM
